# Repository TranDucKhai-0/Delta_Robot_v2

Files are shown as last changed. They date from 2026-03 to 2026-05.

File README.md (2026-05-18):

Project là dự án khóa luận tốt nghiệp.
Dự án làm về nghiên cứu động học và thiết kế cơ khí Robot-Delta-3DOF (3 bậc tự do) chuyển động xoay.

Với các file 3D, bạn hoàn toàn có thể tự chế tạo lại 1 phiên bản Robot giống tôi.

Lệnh clone dự án:
git clone https://github.com/TranDucKhai-0/Delta_Robot_v2.git

Cấu trúc chương trình sẽ điều khiển Robot bằng thông qua Wifi bằng giao thức UDP.
Bạn có thể sử dụng chương trình điều khiển(Robot_Control_v2.py) của tôi, hoặc tự thiết kế chương trình điều khiển của riêng bản thân với giao thức và gói data tương tự.

Môi trường lập trình: PlatformIO, framwork ESP-IDF, trình biên dịch C17.

Môi trường thiết kế: Solidworks 2021, EasyEDA.

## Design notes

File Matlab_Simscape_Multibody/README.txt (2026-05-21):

Bạn có thể chỉnh lại tham số hình học của Robot như a, rf, re, k ở file delta_pararms.m để động học thuật/nghịch có thể tính chính xác.

Sau khi bấm RUN ở Simmulink thì có thể dùng file DoThi_QuyDao.m để hiể thị đồ thị so sánh giữa mô phỏng và thuật toán.

Có thể lưu lại data sau khi mô phỏng bằng file Save_data.m.
Nếu mở data từ Save_data.m thì dùng file Open_data.m.
Với data được mở từ Open_data.m thì hãy sử dụng Open_file_saved.m để xem đồ thị.

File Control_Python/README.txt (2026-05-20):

Kết nối Wifi của Robot: Delta_Robot_v2
                  pass: 12345678

Chạy file Robot_Control_v2.py để điều khiển robot không dây

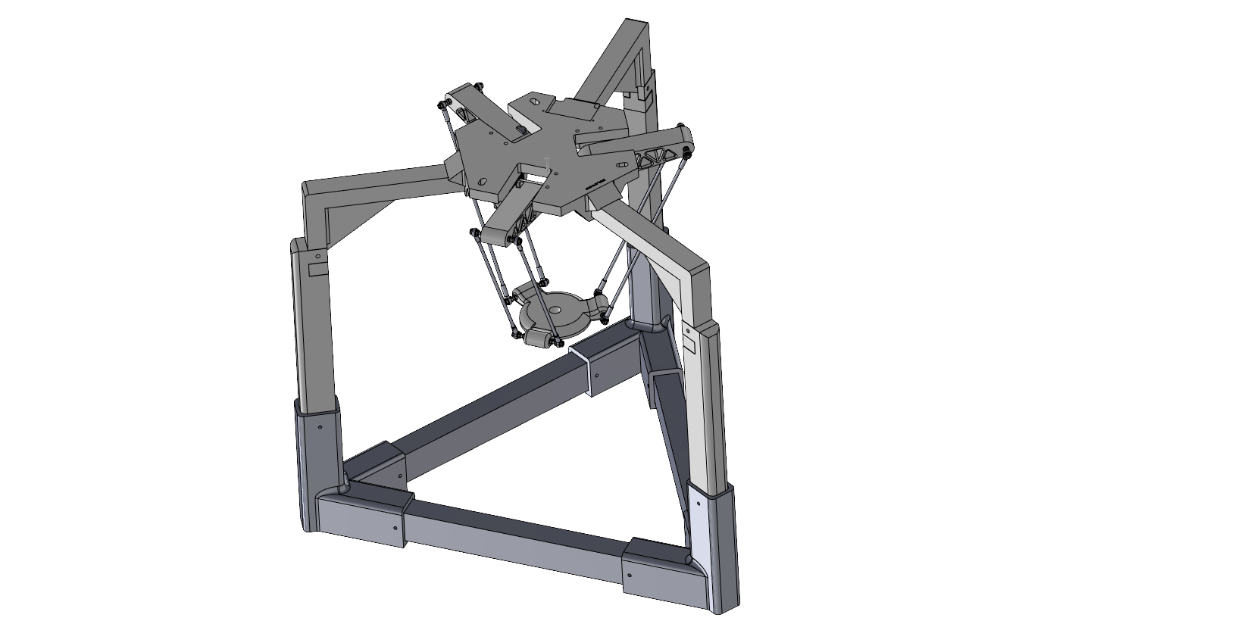
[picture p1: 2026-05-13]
Hardware/Robot_full_body.PNG

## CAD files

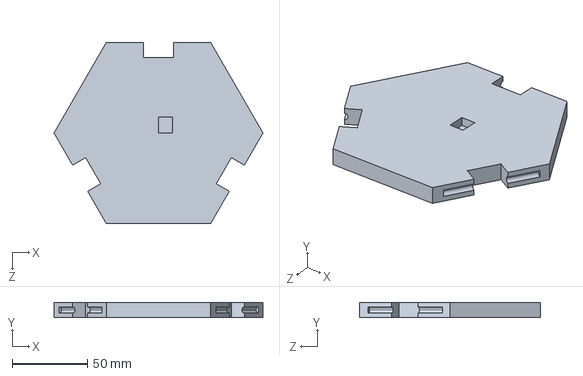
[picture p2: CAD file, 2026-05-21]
Matlab_Simscape_Multibody/de_tinh_Default_sldprt.STEP
138.6 x 10.0 x 120.0 mm

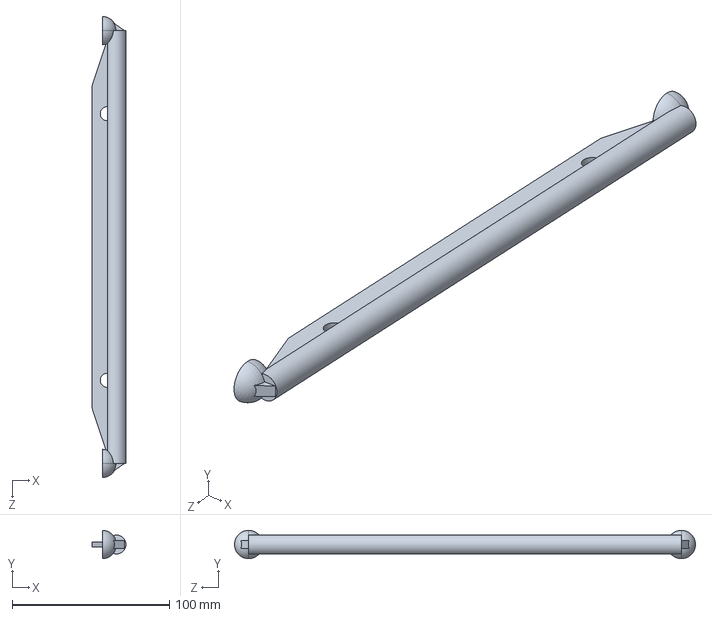
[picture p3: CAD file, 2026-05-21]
Matlab_Simscape_Multibody/Canh_tay_thu_dong_Default_sldprt.STEP
21.5 x 18.0 x 293.0 mm

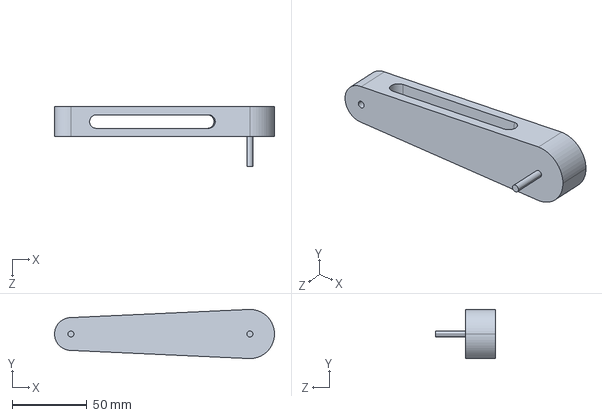
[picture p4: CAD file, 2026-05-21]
Matlab_Simscape_Multibody/Canh_tay_chu_dong_Default_sldprt.STEP
147.5 x 33.0 x 40.0 mm

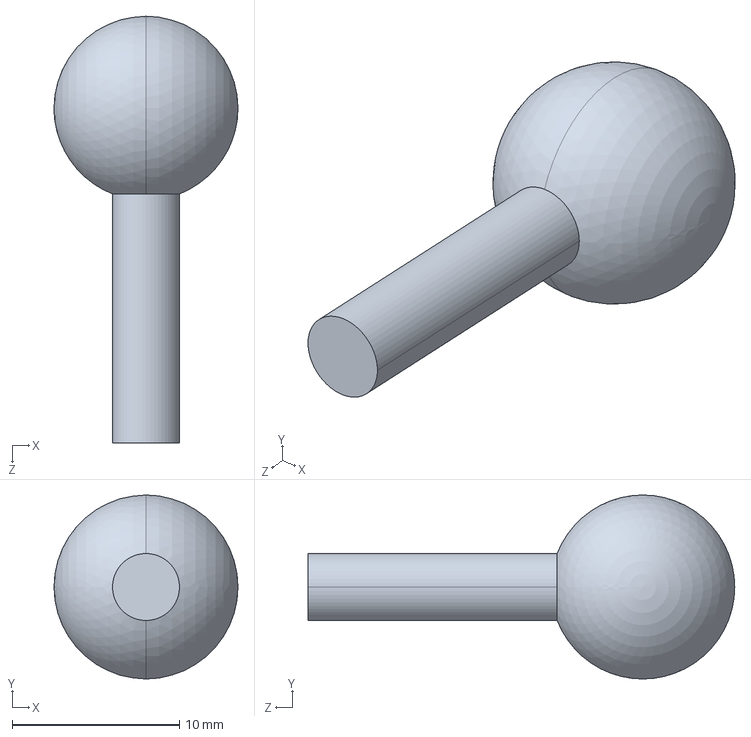
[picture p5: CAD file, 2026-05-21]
Matlab_Simscape_Multibody/Bi_tron_khop_quay_Default_sldprt.STEP
11.0 x 11.0 x 25.5 mm

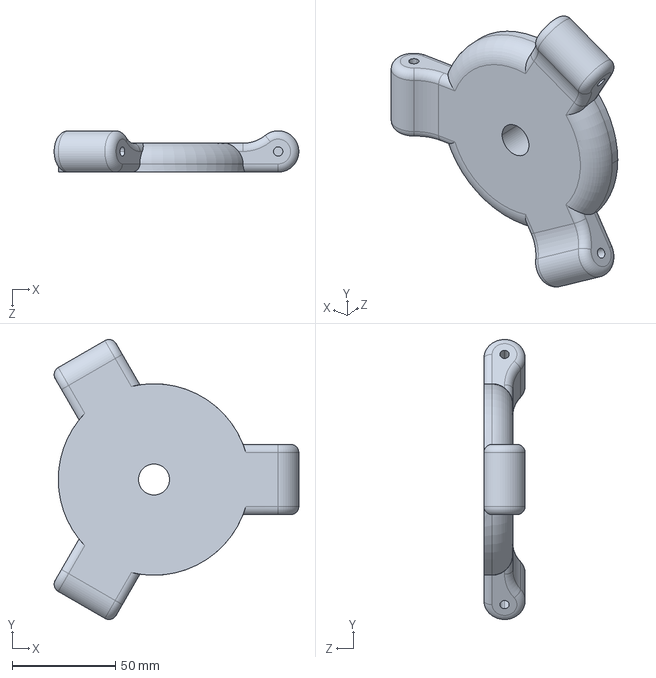
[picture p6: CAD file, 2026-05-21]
Matlab_Simscape_Multibody/De_dong_Default_sldprt.STEP
118.2 x 135.3 x 20.0 mm

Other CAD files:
Hardware/Native_SolidWorks/Robot_full_body.SLDASM
Hardware/Native_SolidWorks/ESP-32_v1.STEP.SLDASM
Hardware/Native_SolidWorks/MG996R SBORKA.STEP.SLDASM
Hardware/Native_SolidWorks/Canh_tay_chu_dong.SLDPRT
Hardware/Native_SolidWorks/Work_Space.SLDPRT
Hardware/Native_SolidWorks/Canh_tay_thu_dong.SLDPRT
Hardware/Native_SolidWorks/Lop_chan_ROBOT.SLDPRT
Hardware/Native_SolidWorks/Tay_thuj_dong_EXEMPLE.SLDPRT
Hardware/Native_SolidWorks/De_dong.SLDPRT
Hardware/Native_SolidWorks/Dem_con.SLDPRT
Hardware/Native_SolidWorks/thanh_don_EXAMPLE.SLDPRT
Hardware/Native_SolidWorks/Thanh_noi_tiep_chan_Robot.SLDPRT
Hardware/Native_SolidWorks/Chot_tay_chu_dong.SLDPRT
Hardware/Native_SolidWorks/59935K14_Ball Joint Rod End.SLDPRT
Hardware/Native_SolidWorks/Bi_tron_khop_quay.SLDPRT
Hardware/Native_SolidWorks/Chan_Robot.SLDPRT
Hardware/Native_SolidWorks/Chan_Robot_duoi.SLDPRT
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

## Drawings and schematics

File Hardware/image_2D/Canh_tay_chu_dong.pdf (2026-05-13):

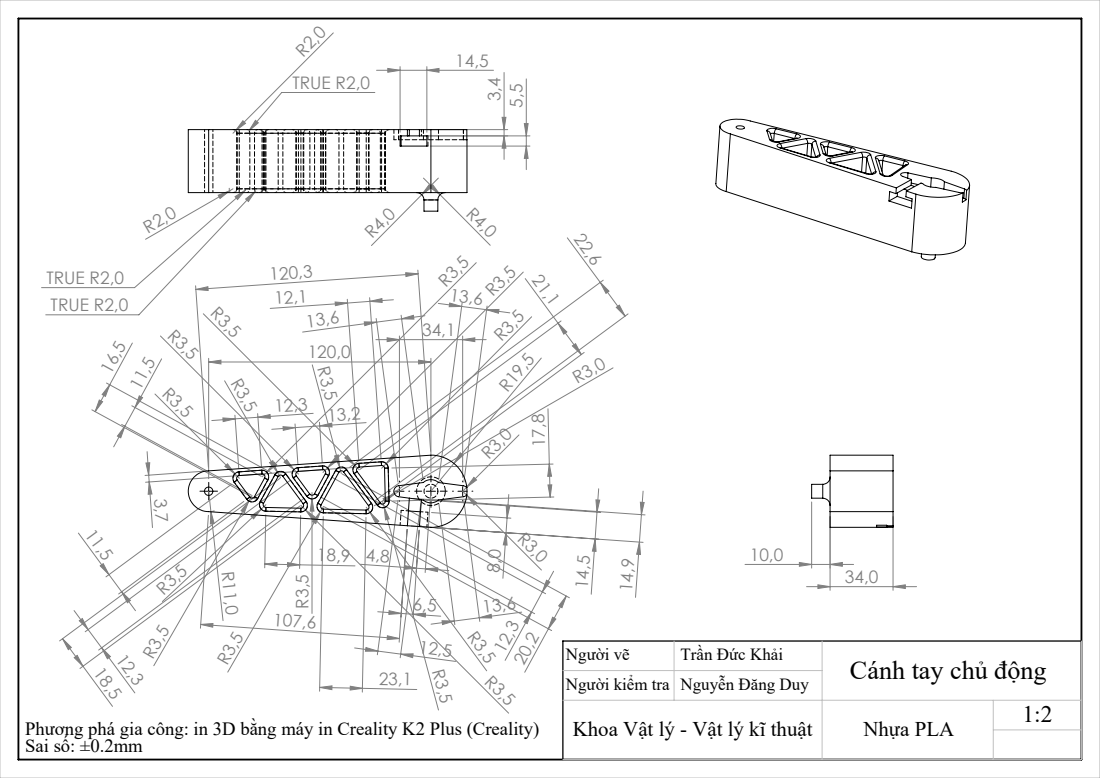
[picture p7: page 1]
TRUE R2,0; TRUE R2,0 TRUE R2,0; Phương phá gia công: in 3D bằng máy in Creality K2 Plus (Creality); Khoa Vật lý - Vật lý kĩ thuật; Nhựa PLA Sai số: ±0.2mm

Người vẽ | Trần Đức Khải | Cánh tay chủ động
Người kiểm tra | Nguyễn Đăng Duy

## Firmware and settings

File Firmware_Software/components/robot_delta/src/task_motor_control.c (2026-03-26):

#include "task_motor_control.h"

#include "arm.h"
#include "globals.h"
#include "type_data.h"
#include "arm.h"
#include "robot_delta.h"
#include "kinematics.h"


#include "freertos/FreeRTOS.h"
#include "freertos/task.h"
#include <math.h>


// Các thông số ép xung cho MG90S (Độ phân giải 14-bit)
// 14-bit có nghĩa là 1 chu kỳ 20ms được chia làm 16384 nấc
#define DUTY_MIN 410  // Tương đương xung 0.5ms (Góc 0 độ)
#define DUTY_MAX 1966 // Tương đương xung 2.0ms (Góc 180 độ)


static void _Robot_Timer_Init() {
    // Tần số 50Hz, Độ phân giải 14-bit
    ledc_timer_config_t ledc_timer = {};
    ledc_timer.speed_mode       = LEDC_HIGH_SPEED_MODE;
    ledc_timer.timer_num        = LEDC_TIMER_0; // 3 Arm xài chung 1 Timer
    ledc_timer.duty_resolution  = LEDC_TIMER_14_BIT;
    ledc_timer.freq_hz          = 50;           // Tần số chuẩn của MG996R (50Hz)
    ledc_timer.clk_cfg          = LEDC_AUTO_CLK;
    ledc_timer_config(&ledc_timer);
}

// Hàm tính góc đầu ra cho 1 cánh tay
static float _Robot_Calculate_Servo_Angle(float angle_rad) {
    // Đổi về Độ (Degrees)
    float angle_deg = angle_rad * 180.0f / M_PI;

    // Bù góc cơ khí (Đưa góc 0 của IK về tâm 90 của Servo)
    float servo_angle = 90.0f - angle_deg;

    // Chặn an toàn cơ khí (Chống gãy nhông Servo)
    if (servo_angle < 0.0f) return 0.0f;
    if (servo_angle > 180.0f) return 180.0f;
    
    return servo_angle;
}

// ánh xạ Xung (Degree -> Duty)
static uint32_t _Robot_Calculate_Duty(float servo_angle) {
    // Ánh xạ tuyến tính từ dải góc (0 - 180) sang dải xung (410 - 1966)
    return DUTY_MIN + (uint32_t)((servo_angle / 180.0f) * (DUTY_MAX - DUTY_MIN));
}

// Giao tiếp phần cứng (Duty -> LEDC)
static void _Robot_Set_PWWM_Duty(arm_object_t *arm, uint32_t duty) {
    // Đẩy tín hiệu xuống thanh ghi phần cứng ESP32
    ledc_set_duty(LEDC_HIGH_SPEED_MODE, arm->_ledc_channel, duty);
    ledc_update_duty(LEDC_HIGH_SPEED_MODE, arm->_ledc_channel);
}

static void _Robot_Write_PIN(arm_object_t *arm, float angle_rad) {
    float safe_angle = _Robot_Calculate_Servo_Angle(angle_rad);
    uint32_t duty = _Robot_Calculate_Duty(safe_angle);
    _Robot_Set_PWWM_Duty(arm, duty);
}

static void _Robot_Write_All_Pins(robot_object_t *p_robot, theta_t *p_theta) {
    _Robot_Write_PIN(&p_robot->_arm_1, p_theta->arm_1);
    _Robot_Write_PIN(&p_robot->_arm_2, p_theta->arm_2);
    _Robot_Write_PIN(&p_robot->_arm_3, p_theta->arm_3);
}



// ================================ Task Điều Khiển Động Cơ (Motor Control) =================================
void Robot_Motor_Control_Task(void *pvParameters){
    // Khởi tạo Timer cho việc xuất xung PWM
    _Robot_Timer_Init();

    theta_t theta_target = {0, 0, 0};
    Robot_Setup_Home_Point(g_p_robot, &theta_target); // Đưa biến robot về điểm home ban đầu

    // Đưa cánh tay về Home
    _Robot_Write_All_Pins(g_p_robot, &theta_target);

    // ngừng một thời gian để đảm bảo các cánh tay đã về vị trí home trước khi cho phép các task khác hoạt động
    vTaskDelay(pdMS_TO_TICKS(2000)); // Đợi 2 giây

    // Cho phép các task bị dừng trước đó hoạt động
    if (g_handle_planner != NULL)
        vTaskResume(g_handle_planner);
    if (g_handle_kinematics != NULL)
        vTaskResume(g_handle_kinematics);

    // luồng chạy chính của task điều khiển động cơ
    while (1) {
        // Kiểm tra có bộ góc mục tiêu mới nào được gửi từ kinematics đến control hay không, không thì cho task này ngủ
        if (xQueueReceive(g_queue_kinematics_to_control, &theta_target, portMAX_DELAY)) {
        _Robot_Write_All_Pins(g_p_robot, &theta_target);     
        }
    }
}

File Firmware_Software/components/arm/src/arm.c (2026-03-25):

#include "arm.h"

static void _Arm_Ledc_Channel_Init(arm_object_t *arm) {
    static ledc_channel_t _next_channel = LEDC_CHANNEL_0;
    arm->_ledc_channel = _next_channel;
    _next_channel = (ledc_channel_t)(_next_channel + 1);

    // Cấu hình Kênh xuất xung ra chân GPIO 
    ledc_channel_config_t ledc_channel = {};
    ledc_channel.speed_mode     = LEDC_HIGH_SPEED_MODE;
    ledc_channel.channel        = arm->_ledc_channel;
    ledc_channel.timer_sel      = LEDC_TIMER_0;
    ledc_channel.intr_type      = LEDC_INTR_DISABLE;
    ledc_channel.gpio_num       = arm->_pin;
    ledc_channel.duty           = 0; // Mới bật lên thì chưa xuất xung
    ledc_channel.hpoint         = 0;
    ledc_channel_config(&ledc_channel);
}

void Arm_Init(arm_object_t *arm, uint8_t pin) {
    // Gán chân GPIO cho arm
    arm->_pin = pin;
    
    // Cấu hình kênh LEDC để xuất xung PWM
    _Arm_Ledc_Channel_Init(arm);
}

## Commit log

2026-03-24 Setup project
    [partitions.csv]
2026-03-24 Setup công tắt chương trình
2026-03-24 Khởi tạo hàm phát wifi
2026-03-24 Khởi tạo task đánh lừa DNS, đưa thiết bị kết nối vs wifi đến trang Upload firmware
2026-03-24 Sửa tên task đánh lừ DNS
2026-03-24 Tạo chức năng OTA cho ESP32 và thêm các hàm đánh chặn đối tượng kết nối wifi
2026-03-24 sửa lỗi không build dc
2026-03-24 đổi tên vài chổ cho đẹp
2026-03-24 Thêm thư mục example
2026-03-24 Tạo kiểu dữ liệu chứa point 3D và bộ góc cánh tay
2026-03-24 gán chân GPIO điều khiển Servo
2026-03-24 sửa file CMake của globals
2026-03-24 đổi tên kiểu dữ liệu trong globals
2026-03-24 sửa tên thư viện include và xóa toán tử !=
2026-03-24 Khởi tạo Queue giao tiếp giữa các core
2026-03-24 thêm include để sữa lỗi biên dịch
2026-03-24 sửa tên hàm khởi chạy chuognw trình
2026-03-24 Tạo task UDP nhận data từ PC(Python)
2026-03-24 thêm điều kiện kiểm tra kết nối UDP, đảm bảo kết nối ổn định
2026-03-24 thêm điều kiện kiểm tra UDP, đảm bảo kết nối ổn định
2026-03-25 tạo hàm khởi tạo đối tượng robot delta
2026-03-25 Thêm thư viện động học thuận/nghịch
2026-03-25 đổi tên hàm động học
2026-03-25 thêm hàm kiểm tra vùng hoạt động hiệu quả
2026-03-25 thêm thư viện toán math_utils.h
2026-03-25 thêm các hàm thuộc đối tượng Robot gọi động học thuận nghịch
2026-03-25 Khai báo 2 task chạy ở core1
2026-03-25 Thêm biến flat cho biến mục tiêu
2026-03-25 đưa typedef ra component riêng và sửa lỗi kèm theo
2026-03-25 Sửa lại hàm bình phương
2026-03-25 thêm Queue chứa bộ góc cho điều khiển cánh tay Robot
2026-03-25 xếp lại moule vừa chia
2026-03-25 Setup task planner và cấp phát bộ nhớ cho biến g_robot
2026-03-25 thêm tín năng tạm dừng task planner, kinematics khi vừa khởi động ESP32
2026-03-25 Tạo obj arm
2026-03-25 khởi tạo các hàm hỗ trợ xuất xung PWM
2026-03-25 sửa chửa ở task motor_control
2026-03-26 sữa lỗi linker
2026-03-26 bố cục lại các biến globals
2026-03-26 thêm Mode homing và thuật toán nội suy tuyến tính
2026-03-26 kích hoạt Call FK ở Homing
2026-03-26 đặt cờ ngắt Homing ở task UDP
2026-03-26 Sửa nhẹ logic hàm call kinematic
2026-03-26 thêm thuật toán bộ lọc thông thấp
2026-03-26 Sữa các lỗi phát xin trong quá trình build
2026-03-26 thêm log để debug
2026-03-26 thêm key lock, để bảo vệ biến thuộc robot
2026-03-26 tóm gọn thuật toán trong math_until
2026-03-26 sửa hàm gọi kinematic
2026-03-26 Tạo logic cho task tính toán kinematic
2026-03-26 Sửa lỗi lặt vặn biên dịch
2026-03-26 Sửa lỗi tính toán ở chế độ Manual
2026-03-27 FIX các lỗi lặt vặt
    [app.c]
2026-03-27 Sửa lỗi homing
2026-03-27 Sửa lỗi nhảy tại chổ Mode Pick and Place
2026-03-27 Bản thiết kế cơ khí Robot
    [Bi_tron_khop_quay.SLDPRT, Canh_tay_chu_dong.SLDPRT, Canh_tay_thu_dong.SLDPRT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]
2026-03-27 Up Full Body Robot 3D
    [Robot_full_body.SLDASM]
2026-03-27 Sửa Robot 3D
    [Robot_full_body.SLDASM]
2026-03-27 Chương trình điều khiển Robot bằng máy tính
2026-03-28 Mô tả dự án
2026-03-28 Mô tả dự án
    Added information about program structure and programming environment.
2026-04-11 feat(drawing 2d): thêm bảng vẻ 2D chi tiết cơ khí
    [Canh_tay_chu_dong.SLDDRW, Canh_tay_thu_dong.SLDDRW, Chan_Robot_duoi.SLDDRW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]
2026-04-16 feat : thêm hình bản vẽ
    [Canh_tay_chu_dong.SLDDRW, Canh_tay_chu_dong.SLDPRT, Canh_tay_thu_dong.SLDDRW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]
2026-05-13 feat and refactor: thêm và sửa lại thiết kế 3D
    [59935K14_Ball Joint Rod End.SLDPRT, Canh_tay_chu_dong.SLDDRW, Canh_tay_chu_dong.SLDPRT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]
2026-05-13 feat: thêm code matlab vẽ vùng hoạt động
2026-05-17 change(task_planer): thây đổi thuật toán pick and place sang quỹ đạo cổng
2026-05-17 change: tái cấu trúc đóng gói dữ liệu pick and place
2026-05-18 fix(robot_delta): sửa chữa cú pháp khiến lỗi biên dịch
    [app.c]
2026-05-18 sửa README
2026-05-18 feat(robot_delta): thêm cấu trúc điều khiển gripper
2026-05-18 sửa cấu trình vận tốc, chân
2026-05-18 Gỡ bỏ .vscode và .esp32dev lỡ push nhầm
2026-05-19 feat(task_kinematics): thêm logic kiểm tra điểm mục tiêu so với điểm hiện tại
2026-05-19 refactor(task_planner): sửa cú pháp bất hợp lý
2026-05-20 reafactory(globals): đổi tham số cấu hình
2026-05-20 feat(udp): thêm cấu trúc id cho gói tin để phân biệt gói mới và gói backup
2026-05-20 feat: thêm cấu trúc id để phân biệt tin mới và backup
2026-05-20 refactor: thây đổi giao diện điều khiển
2026-05-20 thây đổi tham số gripper
2026-05-21 cập nhật thiết kết cánh tay thụ động mới
    [Canh_tay_chu_dong.SLDPRT, Work_Space.SLDPRT]
2026-05-21 thêm folder mô phỏng matlab simscape
    [Bi_tron_khop_quay_Default_sldprt.STEP, Canh_tay_chu_dong_Default_sldprt.STEP, Canh_tay_thu_dong_Default_sldprt.STEP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]
2026-05-21 fix: sửa các lỗi tồn động về mode auto và pick and place
    [gripper.c]
2026-05-21 refacetory(control_python): sửa tham số giao diện
